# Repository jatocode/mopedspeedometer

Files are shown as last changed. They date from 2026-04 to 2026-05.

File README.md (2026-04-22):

# Tänkte bygga en hastighetsmätare av esp32 + gps som fejkar magnetdata

# GATT problem:

Rotorsaken till alla problemen var att ESP32 BLE-tjänsten skapades med för få GATT-handles (15 default) — den sjätte karakteristiken (AUX) registrerades aldrig, vilket fick hela GATT-discovery att fallera med "Not supported".

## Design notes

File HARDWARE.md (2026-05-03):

# Hårdvara – GPS Speedometer Pulse Emulator

## Inköpslista

> Priserna är ungefärliga (april 2026). AliExpress är billigast men har 3–5 veckors leveranstid.
> Electrokit/Kjell ger snabb leverans inom Sverige till något högre pris.

| # | Komponent | Specifikation | Antal | Ca pris | Sök på |
|---|---|---|---|---|---|
| 1 | ESP32 dev board | ESP32-WROOM-32 DevKit v1 (38-pin) | 1 | 45–80 kr | AliExpress / Electrokit |
| 2 | GPS-modul | NEO-6M med keramisk patch-antenn | 1 | 40–70 kr | AliExpress / Amazon |
| 3 | Buck converter-modul | MP1584EN eller LM2596-baserad, in 4–28V, ut adj. | 1 | 15–30 kr | AliExpress / Electrokit |
| 4 | NPN-transistor | 2N2222A, BC337 eller S8050 (TO-92) | 1 (köp 10-pack) | 15–25 kr | Electrokit / Kjell |
| 5 | Motstånd 1 kΩ | 1/4W metallfilm | 1 (köp 100-pack) | 15–30 kr | Electrokit / Kjell |
| 6 | Motstånd 10 kΩ | 1/4W metallfilm | 1 (ingår i samma pack) | — | — |
| 7 | Elektrolytkondensator | 100 µF / 16V (eller 25V), radiell | 1 | < 5 kr | Electrokit |
| 8 | Keramisk kondensator | 100 nF (0,1 µF), 50V | 1 | < 5 kr | Electrokit |
| 9 | Perfboard / gällbräda | 5 × 7 cm enkelsidig | 1 | 10–20 kr | Electrokit / Kjell |
| 10 | Dupont-kablar | Hona–hona 20 cm, 10-pack | 1 pack | 20–35 kr | AliExpress / Electrokit |
| 11 | Skarvkabel fordon | Tunna 0,5 mm² med 12V-anslutning (t.ex. Superseal/AMP) | 0,5 m | 20–40 kr | Biltillbehör / Biltema |
| 12 | Gummigrommets | Ø7 mm kabeldragningsgrommet | 3 | 10–20 kr | Biltema / Biltillbehör |
| 13 | M3-skruvar + muttrar | M3 × 10 mm, rostfri | 4 | 5–10 kr | Bauhaus / Biltema |
| 14 | M3-skruvar montering | M3 × 16 mm + brickor (till moped-ram) | 4 | 5–10 kr | Bauhaus / Biltema |
| 15 | Buntband | 100 × 2,5 mm, svart UV-beständig | 10 st | 10–15 kr | Biltema |
| 16 | Krympslang | Ø3 mm och Ø6 mm, sortiment | 0,5 m | 15–25 kr | Electrokit / Biltema |
| 17 | PLA/PETG-filament | 1,75 mm, valfri färg (för 3D-print) | ~80 g | 25–40 kr | 3D-printutskrift med eget filament |

**Beräknad totalkostnad: ~300–500 kr** (exkl. filament och frakt; beroende på butik)

> **Tips:** Motstånd och transistorer köps med fördel i sortimentsaskar om du inte redan har det –
> sparkade på sikt och kostnaden är densamma för ett 100-pack som för lösa.

---

## Komponentlista

---

## Kopplingsschema

```
FORDON 12V GND ──────────────────────────────────────────────── GND (gemensam)
FORDON 12V +  ──────┬────────────────────────────────────────── 12V-rail
                    │
             ┌──────┴───────┐
             │ Buck converter│   ← ställ till 5.0V (mät med multimeter!)
             │   12V → 5V   │
             └──────┬───────┘
                    │ 5V
                    ├─── 100 µF elektrolyt till GND  │ lång ben (+) mot 5V
                    ├─── 100 nF keramisk till GND    │ placera nära utgången
                    │
           ┌────────┴───────────────────┐
           │                            │
      ESP32 VIN                    NEO-6M VCC
      (onboard AMS1117                  │
       ger 3.3V till chip)         NEO-6M GND ──── GND
                                   NEO-6M TX  ──── ESP32 GPIO16 (UART2 RX)
                                   NEO-6M RX  ──── ESP32 GPIO17 (UART2 TX)

ESP32 GPIO25 ──── 1 kΩ ──── NPN-bas (2N2222)
                             NPN-emitter ──── GND
                             NPN-kollektor ── Instrument sensor-pin
                                             │
                                        10 kΩ pull-up
                                             │
                                            12V-rail
```

> **Glättningskondensatorer:** De två kondensatorerna sitter parallellt direkt vid
> buck-converterns utgång, så nära utgångsplinten som möjligt.
> Elektreolyten (100 µF) hanterar lågfrekvent brus och belastningssvängningar;
> den keramiska (100 nF) filtrerar högfrekvent switching-brus från buck-modulen.
> Elektreolyten är **polariserad** – långt ben (anod +) mot 5V, kort ben med vit rand mot GND.

### Transistorlogik (aktiv-låg puls till instrument)

| GPIO25 | Transistor | Instrument sensor-pin |
|---|---|---|
| LOW | Av (stängt)| 12V (vila) |
| HIGH | På (leder) | ~0V (puls) |

---

## Spänningsförsörjning – detaljer

**Varför buck converter och inte linjärregulator (7805)?**
- 12V → 5V vid 200 mA ger 7V × 0,2A = **1,4 W** värmeutveckling i en 7805 → kräver kylfläns
- En MP1584/LM2596-baserad buck-modul har ~85–90% verkningsgrad → nästintill ingen värme

**Inställning:**
1. Koppla 12V till buck-modulens ingång
2. Mät utspänning med multimeter
3. Vrid potentiometern tills utspänningen är **5,0 V**
4. Koppla sedan ESP32 och GPS-modul

---

## Montering – tips

1. Ställ alltid in buck-modulen till rätt spänning **innan** ESP32 kopplas in.
2. Placera GPS-antenn med fri sikt mot himlen – undvik metallhölje direkt ovanpå.
3. Använd gemensam GND för fordon, buck-modul, ESP32, GPS och transistor.
4. Skydda kretsen i en plastlåda mot fukt och vibrationer.
5. Fäst kablar så att de inte kan vibrera loss – använd buntband eller kabelbindning.

---

## Konfiguration i koden

Justera konstanterna i `mopedspeedometer.ino` för ditt hjul:

| Konstant | Standardvärde | Beskrivning |
|---|---|---|
| `WHEEL_CIRCUMFERENCE_M` | `1.85` | Hjulomkrets i meter: `π × däckdiameter_m` |
| `PULSES_PER_REV` | `1` | Antal pulser per hjulvarv (antal magneter) |

**Beräkna hjulomkrets:**
- Mät däckets ytterdiameter i meter, t.ex. 0,565 m
- Omkrets = π × 0,565 ≈ **1,77 m**
- Alternativt: rulla hjulet ett varv på marken och mät sträckan

**Frekvensexempel:**

| Hastighet | Hjulomkrets | Pulsfrekvens |
|---|---|---|
| 30 km/h | 1,85 m | ~4,5 Hz |
| 50 km/h | 1,85 m | ~7,5 Hz |
| 80 km/h | 1,85 m | ~12,0 Hz |

---

## Verifiering innan montering på moped

1. **Frekvenscheck** – mät GPIO25 med oscilloskop eller logikanalysatorn:
   - Vid 50 km/h och 1,85 m omkrets → förväntat **~7,5 Hz** (halvperiod ~67 ms)
2. **Transistorsteget** – verifiera med multimeter att sensor-pinnen på instrumentet:
   - Är ~12V vid GPIO25 LOW (vila)
   - Dras till ~0V vid GPIO25 HIGH (puls)
3. **Strömförbrukning** – mät total strömförbrukning på 12V-ingång: förväntat **< 200 mA**
4. **GPS-fix** – öppet fönster eller utomhus: vänta på fix (blinkande LED på NEO-6M-modul), kontrollera Serial Monitor i PlatformIO (115200 baud)

### BLE-verifiering (med nRF Connect-appen)

1. Ladda ner **nRF Connect** (iOS / Android) – gratis
2. Öppna appen → **Scan** → leta efter `MopedSpeedo` i listan → tryck **Connect**
3. Öppna servicen `4fafc201-…` → tryck på notify-ikonen (pil nedåt) på t.ex. **Speed**-karakteristiken → hastighetsdata börjar strömma (uppdateras 1 Hz)
4. Testa **AUX-output** (GPIO26):
   - Hitta karakteristiken `beb54843-…` (AUX_OUTPUT)
   - Tryck **Write** → välj format `BYTE` → skriv `01` → GPIO26 går HIGH (enhet på)
   - Skriv `00` → GPIO26 går LOW (enhet av)
5. Kontrollera att Serial Monitor i PlatformIO visar `BLE: client connected` och `BLE: AUX output → ON/OFF`

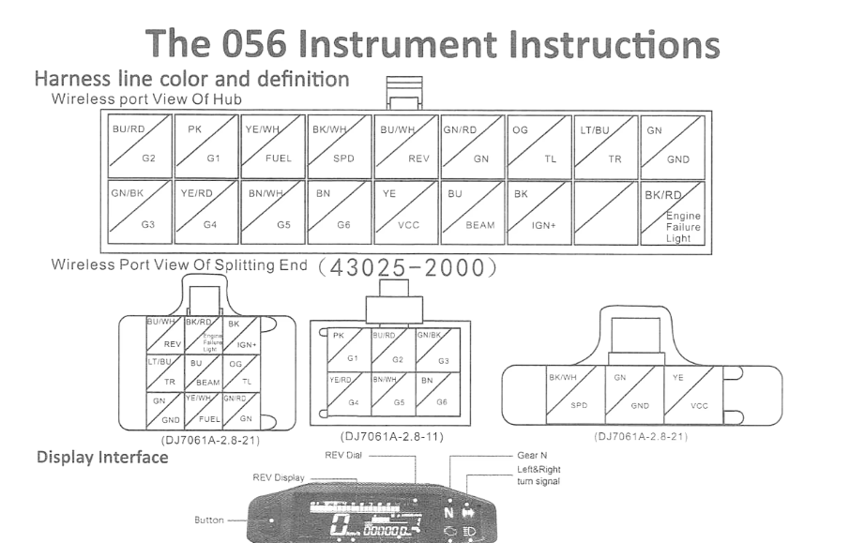
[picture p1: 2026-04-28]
src/instrument-schema-troligt.png

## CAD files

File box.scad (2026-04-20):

// box.scad – Parametric enclosure for GPS Speedometer Pulse Emulator
//
// Components housed:
//   - ESP32 DevKit v1       (52 × 28 mm, M2.5 mount holes 48 × 23.5 mm pitch)
//   - NEO-6M GPS module     (25 × 35 mm, ceramic antenna 18 × 18 mm on top)
//   - Buck converter        (MP1584 / LM2596, 22 × 17 mm)
//   - Transistor + resistors on small perfboard (20 × 20 mm)
//
// Print in PETG or PLA, 0.2 mm layer, 3 perimeters, 20 % infill.
// M3 heat-set inserts recommended for corner screw holes (or thread directly).
// M2.5 heat-set inserts for ESP32 standoffs.
//
// Two parts in this file – use the render switches at the bottom:
//   SHOW_BOTTOM = true / false
//   SHOW_LID    = true / false

// ── Global parameters ────────────────────────────────────────────────────────
$fn = 48;           // arc smoothness

// Inner cavity dimensions
inner_l = 90;       // X length
inner_w = 65;       // Y width
inner_h = 38;       // Z inner height (bottom part)

wall    = 2.5;      // wall / floor / ceiling thickness
corner_r = 3;       // outer corner radius

lid_h   = 8;        // height of lid (including lip)
lip_h   = 4;        // height of snap/press fit lip
lip_gap = 0.3;      // clearance between lid lip and inner wall

// ── Derived outer dimensions ─────────────────────────────────────────────────
outer_l = inner_l + 2 * wall;
outer_w = inner_w + 2 * wall;
outer_h = inner_h + wall;       // floor included, top open for lid

// ── Render switches ──────────────────────────────────────────────────────────
SHOW_BOTTOM = true;
SHOW_LID    = true;

// ── Component positions (from inner floor origin, bottom-left = 0,0) ─────────
// ESP32 DevKit v1 – left side
esp32_x    = 2;
esp32_y    = 2;
esp32_l    = 52;
esp32_w    = 28;
esp32_mh_x = 2;        // mounting hole inset from module edge
esp32_mh_y = 2.25;
esp32_mh_dx = 48;      // hole pitch X
esp32_mh_dy = 23.5;    // hole pitch Y
esp32_mh_d  = 2.7;     // M2.5 clearance
standoff_h  = 4;       // height of standoff above floor
standoff_od = 5;       // standoff outer diameter

// NEO-6M GPS – right side
gps_x  = 58;
gps_y  = 2;
gps_l  = 35;           // module PCB length
gps_w  = 25;           // module PCB width
ant_x  = gps_x + 8.5; // ceramic antenna X offset from inner origin
ant_y  = gps_y + 3.5; // ceramic antenna Y offset
ant_l  = 18;           // antenna width
ant_w  = 18;           // antenna depth
ant_win_thick = 1.0;   // thinned lid wall over antenna (GPS signal window)

// Buck converter – bottom-left, behind ESP32
buck_x = 2;
buck_y = 34;
buck_l = 22;
buck_w = 17;

// Perfboard (transistor + resistors) – bottom-right
perf_x = 58;
perf_y = 30;
perf_l = 20;
perf_w = 20;

// ── Cable entry holes – in the right short wall (max-X face) ─────────────────
// Three Ø7 mm holes for rubber grommets: 12V in, signal out, GND
cable_d    = 7;
cable_z    = 12;           // height from inner floor
cable_y    = [10, 32, 54]; // Y positions of the three holes

// ── M3 corner screws (bottom body → lid) ─────────────────────────────────────
m3_d       = 3.4;          // clearance drill
m3_boss_d  = 7;            // boss / pad outer diameter
m3_inset   = 5;            // distance from outer corner centre to hole centre

// ── Zip-tie slots in the outer base ──────────────────────────────────────────
zt_w  = 4;                 // slot width
zt_h  = 3;                 // slot height through floor
zt_l  = 20;                // slot length
// Positions: pair on each long side, centred ± 20 mm from middle
zt_y_pairs = [-20, 20];    // Y offset from centre

// ── M3 mounting holes in base (for bolting to moped frame) ───────────────────
mount_d     = 3.4;
mount_boss_d = 8;
mount_inset = 7;           // from outer edge
// Four corners of the outer footprint

// ─────────────────────────────────────────────────────────────────────────────
// Helper modules
// ─────────────────────────────────────────────────────────────────────────────

module rounded_box(l, w, h, r) {
    hull() {
        for (xi = [r, l - r], yi = [r, w - r])
            translate([xi, yi, 0]) cylinder(h=h, r=r);
    }
}

module rounded_box_bottom(l, w, h, r) {
    // Solid rounded-rectangle prism with flat bottom
    rounded_box(l, w, h, r);
}

module m3_corner_bosses(h) {
    // Four M3 boss cylinders at inner corners of outer shell
    positions = [
        [m3_inset,             m3_inset,            ],
        [outer_l - m3_inset,   m3_inset,            ],
        [m3_inset,             outer_w - m3_inset,  ],
        [outer_l - m3_inset,   outer_w - m3_inset,  ]
    ];
    for (p = positions)
        translate([p[0], p[1], 0]) cylinder(h=h, d=m3_boss_d);
}

module m3_corner_holes(h) {
    positions = [
        [m3_inset,             m3_inset,            ],
        [outer_l - m3_inset,   m3_inset,            ],
        [m3_inset,             outer_w - m3_inset,  ],
        [outer_l - m3_inset,   outer_w - m3_inset,  ]
    ];
    for (p = positions)
        translate([p[0], p[1], -1]) cylinder(h=h + 2, d=m3_d);
}

// ─────────────────────────────────────────────────────────────────────────────
// BOTTOM PART
// ─────────────────────────────────────────────────────────────────────────────

module bottom() {
    difference() {
        union() {
            // Outer shell (open top)
            difference() {
                rounded_box_bottom(outer_l, outer_w, outer_h, corner_r);
                // Hollow out interior
                translate([wall, wall, wall])
                    cube([inner_l, inner_w, outer_h]); // open top
            }

            // M3 corner bosses (extend from floor)
            translate([0, 0, 0]) m3_corner_bosses(outer_h);

            // ESP32 standoffs
            translate([wall + esp32_x + esp32_mh_x,
                       wall + esp32_y + esp32_mh_y, wall]) {
                for (xi = [0, esp32_mh_dx], yi = [0, esp32_mh_dy])
                    translate([xi, yi, 0])
                        cylinder(h=standoff_h, d=standoff_od);
            }

            // Component trays (raised rim around GPS and buck converter)
            // NEO-6M tray – 1 mm rim, 1 mm floor raised 0 mm (sits on standoffs
            // not needed for GPS; thin retaining lip sufficient)
            translate([wall + gps_x - 1, wall + gps_y - 1, wall])
                difference() {
                    cube([gps_l + 2, gps_w + 2, 2]);
                    translate([1, 1, 1]) cube([gps_l, gps_w, 3]);
                }

            // Buck converter tray
            translate([wall + buck_x - 1, wall + buck_y - 1, wall])
                difference() {
                    cube([buck_l + 2, buck_w + 2, 2]);
                    translate([1, 1, 1]) cube([buck_l, buck_w, 3]);
                }
        }

        // ── Subtractions ────────────────────────────────────────────────────

        // M3 corner screw holes through bosses
        m3_corner_holes(outer_h);

        // M2.5 holes through ESP32 standoffs
        translate([wall + esp32_x + esp32_mh_x,
                   wall + esp32_y + esp32_mh_y, 0]) {
            for (xi = [0, esp32_mh_dx], yi = [0, esp32_mh_dy])
                translate([xi, yi, -1])
                    cylinder(h=standoff_h + wall + 2, d=esp32_mh_d);
        }

        // Cable entry holes – right short wall (X = outer_l face)
        for (cy = cable_y)
            translate([outer_l - wall - 0.01, wall + cy, wall + cable_z])
                rotate([0, 90, 0])
                    cylinder(h=wall + 1, d=cable_d);

        // Zip-tie slots – through outer bottom floor on both long sides
        // Side Y=0
        for (dy = zt_y_pairs)
            translate([outer_l / 2 + dy - zt_l / 2, -0.01, -0.01])
                cube([zt_l, zt_w + 0.01, zt_h + 0.01]);

        // Side Y=outer_w
        for (dy = zt_y_pairs)
            translate([outer_l / 2 + dy - zt_l / 2,
                       outer_w - zt_w, -0.01])
                cube([zt_l, zt_w + 0.01, zt_h + 0.01]);

        // Moped mounting holes through base – 4 corners
        mount_positions = [
            [mount_inset,             mount_inset            ],
            [outer_l - mount_inset,   mount_inset            ],
            [mount_inset,             outer_w - mount_inset  ],
            [outer_l - mount_inset,   outer_w - mount_inset  ]
        ];
        for (p = mount_positions)
            translate([p[0], p[1], -1])
                cylinder(h=wall + 2, d=mount_d);
    }

    // Countersunk pads (raised boss on underside not needed – flat base is fine)
    // Label emboss on outer side wall
    translate([wall + 2, -0.4, wall + 4])
        rotate([90, 0, 0])
            linear_extrude(height=0.5)
                text("GPS SPEEDOMETER", size=5, font="Liberation Sans:style=Bold");
}

// ─────────────────────────────────────────────────────────────────────────────
// LID
// ─────────────────────────────────────────────────────────────────────────────
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

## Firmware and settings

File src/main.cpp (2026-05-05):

// src/main.cpp
// GPS-driven pulse emulator – replaces magnetic wheel sensor
// + BLE GATT server for live telemetry and remote toggle output
//
// Wiring:
//   NEO-6M TX   → ESP32 GPIO16 (UART2 RX)
//   ESP32 GPIO25 → 1kΩ → NPN base  → instrument pulse (12V active-low)
//   ESP32 GPIO26 → transistor/relay → toggleable aux output
//
// BLE Service UUID : 4fafc201-1fb5-459e-8fcc-c5c9c331914b
// Characteristics:
//   SPEED_KMH   (notify, float32 little-endian, km/h)
//   HEADING     (notify, float32, degrees)
//   ALTITUDE    (notify, float32, metres)
//   SATELLITES  (notify, uint8)
//   FIX_STATUS  (notify, uint8  0=no fix 1=fix)
//   AUX_OUTPUT  (read/write, uint8  0=off 1=on)  – controls GPIO26
//
// Libraries:
//   mikalhart/TinyGPSPlus  (platformio.ini)
//   BLE / WiFi / ArduinoOTA (built-in ESP32 Arduino Core, no extra dep)
//
// OTA:
//   Disabled by default to save ~20-40 KB flash.
//   To enable: uncomment 'build_flags = -D ENABLE_OTA' in platformio.ini.
//   After first USB flash the board is reachable as 'moped-speedo' on the LAN.
//   In PlatformIO: Upload → select 'moped-speedo.local' as upload target.
//   WiFi credentials live in include/secrets.h (gitignored).

#include <Arduino.h>
#include <HardwareSerial.h>
#include <TinyGPS++.h>
#include <BLEDevice.h>
#include <BLEServer.h>
#include <BLEUtils.h>
#include <BLE2902.h>   // CCCD descriptor – enables client notifications
#include <WiFi.h>
#ifdef ENABLE_OTA
#include <ArduinoOTA.h>
#endif
#include <WebServer.h>
#include "secrets.h"   // #define WIFI_SSID / WIFI_PASSWORD (gitignored)

// ── Configuration ──────────────────────────────────────────────────────────────
const float    WHEEL_CIRCUMFERENCE_M = 1.85f;
const int      PULSES_PER_REV        = 1;

const uint32_t LOG_INTERVAL_MS       = 2000;  // ms between track log entries
const int      LOG_MAX_ENTRIES       = 1000;  // max entries stored in RAM

const int   PULSE_OUTPUT_PIN = 25;   // → NPN base, instrument pulse
const int   AUX_OUTPUT_PIN   = 26;   // → transistor/relay, toggleable aux
const int   STATUS_LED_PIN   = 5;    // built-in LED, mirrors AUX state

const int   GPS_RX_PIN = 16;
const int   GPS_TX_PIN = 17;
const long  GPS_BAUD   = 9600;

constexpr char DEVICE_NAME[]     = "MopedSpeedo";
constexpr char SERVICE_UUID[]    = "4fafc201-1fb5-459e-8fcc-c5c9c331914b";
constexpr char CHR_SPEED[]       = "beb5483e-36e1-4688-b7f5-ea07361b26a8";
constexpr char CHR_HEADING[]     = "beb5483f-36e1-4688-b7f5-ea07361b26a8";
constexpr char CHR_ALTITUDE[]    = "beb54840-36e1-4688-b7f5-ea07361b26a8";
constexpr char CHR_SATELLITES[]  = "beb54841-36e1-4688-b7f5-ea07361b26a8";
constexpr char CHR_FIX_STATUS[]  = "beb54842-36e1-4688-b7f5-ea07361b26a8";
constexpr char CHR_AUX_OUTPUT[]  = "beb54843-36e1-4688-b7f5-ea07361b26a8";
constexpr char CHR_IP_ADDRESS[]  = "beb54844-36e1-4688-b7f5-ea07361b26a8";
constexpr char CHR_WHEEL_CIRC[]  = "beb54845-36e1-4688-b7f5-ea07361b26a8";
constexpr char CHR_PULSES[]      = "beb54846-36e1-4688-b7f5-ea07361b26a8";
// ──────────────────────────────────────────────────────────────────────────────

HardwareSerial gpsSerial(2);
TinyGPSPlus    gps;

hw_timer_t   *pulseTimer  = nullptr;
volatile bool timerEnabled = false;

// ── Track log ─────────────────────────────────────────────────────────────────
struct TrackPoint {
  uint32_t ms;
  float    lat;
  float    lon;
  float    speedKmh;
  float    freq_hz;
};

TrackPoint trackLog[LOG_MAX_ENTRIES];
int        trackCount = 0;

void logTrackPoint(float lat, float lon, float speedKmh, float freq_hz) {
  if (trackCount >= LOG_MAX_ENTRIES) return;  // full – stop silently
  trackLog[trackCount++] = { millis(), lat, lon, speedKmh, freq_hz };
}
// ──────────────────────────────────────────────────────────────────────────────

// Latest telemetry – updated each GPS cycle, read by HTTP handler
struct Telemetry {
  float   speedKmh  = 0;
  float   heading   = 0;
  float   altitude  = 0;
  uint8_t satellites = 0;
  uint8_t fixStatus  = 0;
  uint8_t auxOutput  = 0;
} telem;

// BLE handles
BLEServer          *bleServer    = nullptr;
BLECharacteristic  *chrSpeed     = nullptr;
BLECharacteristic  *chrHeading   = nullptr;
BLECharacteristic  *chrAltitude  = nullptr;
BLECharacteristic  *chrSats      = nullptr;
BLECharacteristic  *chrFixStatus = nullptr;
BLECharacteristic  *chrAux       = nullptr;
BLECharacteristic  *chrIpAddress = nullptr;
BLECharacteristic  *chrWheelCirc = nullptr;
BLECharacteristic  *chrPulses    = nullptr;
bool                bleConnected = false;

// ── BLE server callbacks ───────────────────────────────────────────────────────
class ServerCallbacks : public BLEServerCallbacks {
  void onConnect(BLEServer *)    override { bleConnected = true;  Serial.println("BLE: client connected"); }
  void onDisconnect(BLEServer *s) override {
    bleConnected = false;
    Serial.println("BLE: client disconnected – restarting advertising");
    s->startAdvertising();
  }
};

// ── AUX write callback ─────────────────────────────────────────────────────────
class AuxWriteCallback : public BLECharacteristicCallbacks {
  void onWrite(BLECharacteristic *c) override {
    uint8_t val = c->getValue().length() ? c->getValue()[0] : 0;
    val = val ? 1 : 0;                          // sanitise to 0 or 1
    digitalWrite(AUX_OUTPUT_PIN, val);
    digitalWrite(STATUS_LED_PIN, !val);         // active-low LED: invert AUX state
    telem.auxOutput = val;
    c->setValue(&val, 1);                       // echo back confirmed state
    Serial.printf("BLE: AUX output → %s\n", val ? "ON" : "OFF");
  }
};

// ── Pulse timer ISR ────────────────────────────────────────────────────────────
void IRAM_ATTR onTimer() {
  if (timerEnabled) {
    digitalWrite(PULSE_OUTPUT_PIN, !digitalRead(PULSE_OUTPUT_PIN));
  } else {
    digitalWrite(PULSE_OUTPUT_PIN, LOW);
  }
}

static void sendCommand(const char *cmd) {
  gpsSerial.print(cmd);
  gpsSerial.print("\r\n");
  delay(200);
}

void setPulseFrequency(float freq_hz) {
  timerAlarmDisable(pulseTimer);
  if (freq_hz < 0.05f) {
    timerEnabled = false;
    digitalWrite(PULSE_OUTPUT_PIN, LOW);
    return;
  }
  uint64_t half_period_us = (uint64_t)(500000.0f / freq_hz);
  timerRestart(pulseTimer);
  timerAlarmWrite(pulseTimer, half_period_us, true);
  timerEnabled = true;
  timerAlarmEnable(pulseTimer);
}

// ── Helper: write float to a notify characteristic ────────────────────────────
void notifyFloat(BLECharacteristic *c, float val) {
  c->setValue(reinterpret_cast<uint8_t *>(&val), sizeof(val));
  if (bleConnected) c->notify();
}

void notifyUint8(BLECharacteristic *c, uint8_t val) {
  c->setValue(&val, 1);
  if (bleConnected) c->notify();
}

// ── BLE setup helper ───────────────────────────────────────────────────────────
BLECharacteristic *makeNotify(BLEService *svc, const char *uuid) {
  BLECharacteristic *c = svc->createCharacteristic(
      uuid, BLECharacteristic::PROPERTY_READ | BLECharacteristic::PROPERTY_NOTIFY);
  c->addDescriptor(new BLE2902());
  return c;
}

void setupBLE() {
  BLEDevice::init(DEVICE_NAME);
  bleServer = BLEDevice::createServer();
  bleServer->setCallbacks(new ServerCallbacks());

  // 9 characteristics (7 notify + 2 read-only) × 2-3 handles + 1 service → use 39 for headroom.
  BLEService *svc = bleServer->createService(BLEUUID(SERVICE_UUID), 39);

  chrSpeed    = makeNotify(svc, CHR_SPEED);
  chrHeading  = makeNotify(svc, CHR_HEADING);
  chrAltitude = makeNotify(svc, CHR_ALTITUDE);
  chrSats     = makeNotify(svc, CHR_SATELLITES);
  chrFixStatus = makeNotify(svc, CHR_FIX_STATUS);

  // IP address: read + notify, UTF-8 string, updated once WiFi connects
  chrIpAddress = makeNotify(svc, CHR_IP_ADDRESS);
  chrIpAddress->setValue("0.0.0.0");

  // Read-only config: wheel circumference (float32 LE) and pulses/rev (uint8)
  chrWheelCirc = svc->createCharacteristic(CHR_WHEEL_CIRC, BLECharacteristic::PROPERTY_READ);
  float circ = WHEEL_CIRCUMFERENCE_M;
  chrWheelCirc->setValue(reinterpret_cast<uint8_t *>(&circ), sizeof(float));

  chrPulses = svc->createCharacteristic(CHR_PULSES, BLECharacteristic::PROPERTY_READ);
  uint8_t ppr = (uint8_t)PULSES_PER_REV;
  chrPulses->setValue(&ppr, 1);

  // AUX: read + write + notify
  chrAux = svc->createCharacteristic(
      CHR_AUX_OUTPUT,
      BLECharacteristic::PROPERTY_READ |
      BLECharacteristic::PROPERTY_WRITE |
      BLECharacteristic::PROPERTY_NOTIFY);
  chrAux->addDescriptor(new BLE2902());
  chrAux->setCallbacks(new AuxWriteCallback());
  uint8_t off = 0;
  chrAux->setValue(&off, 1);

  svc->start();

  BLEAdvertising *adv = BLEDevice::getAdvertising();
  adv->addServiceUUID(SERVICE_UUID);
  adv->setScanResponse(true);
  BLEDevice::startAdvertising();
  Serial.printf("BLE: advertising as '%s'\n", DEVICE_NAME);
}

// ── WiFi + OTA setup ──────────────────────────────────────────────────────────
WebServer httpServer(80);

void setupWiFi() {
  Serial.printf("WiFi: connecting to '%s'", WIFI_SSID);
  WiFi.mode(WIFI_STA);
  WiFi.begin(WIFI_SSID, WIFI_PASSWORD);

  // Non-blocking: try for up to 10 s, continue without OTA on failure
  uint32_t t0 = millis();
  while (WiFi.status() != WL_CONNECTED && millis() - t0 < 10000) {
    delay(250);
    Serial.print('.');
  }

  if (WiFi.status() != WL_CONNECTED) {
    Serial.println("\nWiFi: not connected – OTA disabled");
    return;
  }

  Serial.printf("\nWiFi: connected  IP %s\n", WiFi.localIP().toString().c_str());

  // Publish IP over BLE so the client can find the HTTP endpoint
  String ip = WiFi.localIP().toString();
  chrIpAddress->setValue(ip.c_str());
  if (bleConnected) chrIpAddress->notify();

#ifdef ENABLE_OTA
  ArduinoOTA.setHostname("moped-speedo");
  ArduinoOTA.onStart([]()  { Serial.println("OTA: start"); });
  ArduinoOTA.onEnd([]()    { Serial.println("\nOTA: done"); });
  ArduinoOTA.onProgress([](unsigned int done, unsigned int total) {
    Serial.printf("OTA: %u%%\r", done * 100 / total);
  });
  ArduinoOTA.onError([](ota_error_t e) {
    Serial.printf("OTA error [%u]\n", e);
  });
  ArduinoOTA.begin();
  Serial.println("OTA: ready – hostname 'moped-speedo'");
#endif

  httpServer.on("/", []() {
    char buf[224];
    snprintf(buf, sizeof(buf),
      "{\"speed_kmh\":%.2f,\"heading\":%.2f,\"altitude\":%.2f,"
      "\"satellites\":%u,\"fix_status\":%u,\"aux_output\":%u,"
      "\"ip\":\"%s\"}",
      telem.speedKmh, telem.heading, telem.altitude,
      telem.satellites, telem.fixStatus, telem.auxOutput,
      WiFi.localIP().toString().c_str());
    httpServer.sendHeader("Access-Control-Allow-Origin", "*");
    httpServer.send(200, "application/json", buf);
  });

  // Stream track log as CSV – chunked to avoid building a giant string in RAM
  httpServer.on("/track.csv", []() {
    httpServer.sendHeader("Access-Control-Allow-Origin", "*");
    httpServer.sendHeader("Content-Disposition", "attachment; filename=track.csv");
    httpServer.setContentLength(CONTENT_LENGTH_UNKNOWN);
    httpServer.send(200, "text/csv", "");
    httpServer.sendContent("#,ms,lat,lon,speed_kmh,freq_hz\n");
    char row[96];
    for (int i = 0; i < trackCount; i++) {
      const TrackPoint &p = trackLog[i];
      snprintf(row, sizeof(row), "%d,%lu,%.6f,%.6f,%.2f,%.4f\n",
               i + 1, (unsigned long)p.ms, p.lat, p.lon, p.speedKmh, p.freq_hz);
      httpServer.sendContent(row);
    }
    httpServer.sendContent("");  // end chunked response
    Serial.printf("HTTP: /track.csv served %d entries\n", trackCount);
  });

  httpServer.begin();
  Serial.println("HTTP: server started on port 80 – /track.csv available");
}

// ─────────────────────────────────────────────────────────────────────────────
void setup() {
  Serial.begin(115200);

  gpsSerial.begin(GPS_BAUD, SERIAL_8N1, GPS_RX_PIN, GPS_TX_PIN);
  sendCommand("$PMTK220,200*2C");   // 5 Hz = every 200 ms
  sendCommand("$PMTK314,0,1,0,1,0,0,0,0,0,0,0,0,0,0,0,0,0,0,0"); // example: RMC+GGA only
  
  pinMode(PULSE_OUTPUT_PIN, OUTPUT);
  digitalWrite(PULSE_OUTPUT_PIN, LOW);

  pinMode(AUX_OUTPUT_PIN, OUTPUT);
  digitalWrite(AUX_OUTPUT_PIN, LOW);

  pinMode(STATUS_LED_PIN, OUTPUT);
  digitalWrite(STATUS_LED_PIN, LOW);

  pulseTimer = timerBegin(0, 80, true);
  timerAttachInterrupt(pulseTimer, &onTimer, true);
  timerAlarmWrite(pulseTimer, 100000, true);

  setupBLE();
  setupWiFi();

  Serial.println("GPS Speedometer starting – waiting for fix...");
}

void loop() {
#ifdef ENABLE_OTA
  ArduinoOTA.handle();
#endif
  httpServer.handleClient();
  while (gpsSerial.available()) {
    gps.encode(gpsSerial.read());
  }

  if (gps.speed.isUpdated()) {
    bool hasFix = gps.location.isValid() && gps.speed.isValid();

    float speedKmh  = hasFix ? gps.speed.kmph()    : 0.0f;
    float heading   = hasFix ? gps.course.deg()    : 0.0f;
    float altitude  = hasFix ? (float)gps.altitude.meters() : 0.0f;
    uint8_t sats    = gps.satellites.isValid() ? (uint8_t)gps.satellites.value() : 0;
    uint8_t fixSt   = hasFix ? 1 : 0;

    telem.speedKmh   = speedKmh;
    telem.heading    = heading;
    telem.altitude   = altitude;
    telem.satellites = sats;
    telem.fixStatus  = fixSt;

    // Pulse output
    float freq_hz = 0;
    if (hasFix) {
      freq_hz = (gps.speed.mps() / WHEEL_CIRCUMFERENCE_M) * PULSES_PER_REV;
      setPulseFrequency(freq_hz);
      Serial.printf("Speed: %.1f km/h → %.2f Hz (Hdg: %.0f°  Alt: %.0fm  Satellites: %d)\n",
                    speedKmh, freq_hz, heading, altitude, sats);
    } else {
      setPulseFrequency(0);
      Serial.printf("No fix  (sats: %d)\n", sats);
    }

    // Track logging – record a point every LOG_INTERVAL_MS when we have a fix
    static uint32_t lastLog = 0;
    if (hasFix && millis() - lastLog >= LOG_INTERVAL_MS) {
      lastLog = millis();
      logTrackPoint(gps.location.lat(), gps.location.lng(), speedKmh, freq_hz);
    }

    // BLE notifications
    notifyFloat(chrSpeed,    speedKmh);
    notifyFloat(chrHeading,  heading);
    notifyFloat(chrAltitude, altitude);
    notifyUint8(chrSats,     sats);
    notifyUint8(chrFixStatus, fixSt);
  }
}

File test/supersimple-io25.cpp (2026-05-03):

#include <Arduino.h>

void setup() {
  Serial.begin(115200);
  pinMode(25, OUTPUT);
  Serial.println("IO25 toggle test – 1 s on / 1 s off");
}

void loop() {
  digitalWrite(25, HIGH);
  Serial.println("IO25 HIGH");
  delay(1000);
  digitalWrite(25, LOW);
  Serial.println("IO25 LOW");
  delay(1000);
}

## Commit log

2026-04-20 gjorde en låda
    [box.scad]
2026-04-22 Enable connection to all Bluetooth devices and add status LED functionality
2026-04-28 Add kontaktdon.md with pin and keyword data
2026-05-03 la till två varianter för att felsöka neo 6
2026-05-05 Försöker sätta 5Hz uppdatering
    Added sendCommand function to facilitate GPS command sending.
